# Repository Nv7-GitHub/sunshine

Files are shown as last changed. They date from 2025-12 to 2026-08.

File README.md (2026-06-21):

# Sunshine Combat Robot
This is the code for a 1lb melty-brain combat robot. This is a combat robot whose body spins and the wheel speeds are modulated while spinning for translation. There are 3 main components to this robot:

- Robot brain (sunshine_brain): ESP32-S3, which reads the sensors, does the processing, and sends the telemetry via ESP-now to the receiver and receives motion commands and safety-related commands (e.g. enable, disable, etc.)
- Receiver (sunshine_receiver): ESP32-S3, which receives the telemetry and sends it to the host app as well as sends out telemetry commands from the host app
- Host app (sunshine_app): Graphs data, displays telemetry, saves logs to files, handles replay (has to interact with sunshine_brain code for this) and simulation

## Tech stack
All embedded code will be implemented via platform IO. The host app code will be Tauri with React for the frontend. For replay (explained below), the brain code that is above the IO layer has to be very encapsulated so that it can be called from the Tauri rust code.

## Replay
The core concept of this project is IO layers and replay. The core sensors: **time (precise)**, wheel eRPM, ESP-NOW RSSI, magnetometer reading, battery voltage, control inputs from the driver, and accelerometer readings are all sampled at 1kHz and logged via telemetry. 

All the brain code processes these inputs (which are below the IO layer) and runs code that affects the **state**. The state is every variable that changes over time as a result of previous inputs. This should just be the external and internal states of any filters being used. 

The telemetry packets are sent out at 50 Hz, so each packet should include two state snapshots — one at the start of the packet and one at its midpoint (the 10th of its 20 samples), giving the real state at 100 Hz — and then the 20 IO layer samples that happened since the start state. The two states let the host both initialize the filters and double-check the replay against the real state twice per packet. This will minimize data usage because the host app can simply receive the state to initialize the filters and then run replay from there on. In the log files, the real state is likewise logged at 100 Hz (two snapshots per 50 Hz frame; theoretically you could even do it once but I want to be able to always have something to double-check the replay against and/or a way to handle changed code since you collected the telemetry) and the data below the IO layer is logged at the full 1kHz. Variables are NOT logged — they are a pure function of state + inputs, so the host always recomputes them (both the real and replayed versions).

The replay should use the ACTUAL robot code and just feed it a different source of IO layers instead of the raw sensors. So if you make a code change, you could re-run the code using the logged telemetry data and see if it fixes a bug that is occurring, for example.

This IO layer concept is important because it lets you implement simulation, where instead of having the receiver managing state you just implement a basic simulation of the motors and how it affects the sensors in an ideal world and then you can simulate the robot fully on the computer, once again just feeding the simulated sensor data into the IO layer.

In addition to the **state** and **inputs** (data below the IO layer) you also have the **variables** - data that is calculated from the state or inputs without any historical components. This is also logged at 50 Hz, but never sent over telemetry, just logged by the host app. This is once again so that if code changes occur you don't lose the data that was produced by the old code, which is necessary for determining if changes actually led to fixes. 

Replay is designed with AI assistance in mind. Develop Claude skills to aid with debugging code with validation via replay and simulation in parallel to this. Design everything with debugging and ugpradeability in mind. Changing what's in the state, what the inputs are, etc. should be easy and backwards-compatible (so old log data should still be usable). Adding a new variable (especially to the state and variables, which I anticipate changing a lot) should be very easy and well documented for future AI sessions along with the codebase in general.

## Robot brain

The robot brain has the two components mentioned before: below the IO layer, and above the IO layer. Everything above the IO layer has to be able to be run both on the host computer as well as the robot, so it should never interact with hardware directly and should be able to easily be compiled and run on a variety of host computer platforms. For below the IO layer, here is the hardware map:

## Hardware map
IMU is an ADXL375, 11mm from the center of the robot (this is important for calculating ang vel from the centripetal accel). The IMU is rotated 45 degrees so it saturates less.
- IO8: IMU_INT1
- IO9: IMU_INT2
- IO10: IMU_CS
- IO11: IMU_MOSI
- IO12: IMU_SCK
- IO13: IMU_MISO

Mag is LIS3MDL
- IO14: MAG_DRDY
- IO15: MAG_MOSI
- IO16: MAG_SCK
- IO17: MAG_MISO
- IO18: MAG_CS
- IO21: MAG_INT

There is an LED connected to IO38 that can be PWMed. It's connected to the gate of a low side switch so you drive it high to turn on the LEDs.

IO7 is connected with a voltage divider (2kohm high, one kohm low) to the battery positive terminal

IO4 is the signal pin of the left wheel ESC (S1), IO5 is for the right wheel ESC (S2). Use bidirectional DShot 600.

USB is connected, so you can use USB for debugging info

## Core splitting
There are 3 overall tasks running on the brain: telemetry, navigation, and control. 

### Telemetry
Telemetry should be running on the ESP32 core that is meant for telemetry. The data is getting sent out at a fixed 50 Hz and should be received from the transmitter at 500 Hz. This core should receive state (the history, or maybe it buffers the history itself but as explained earlier in each packet there's the state and then the 50 subsequent inputs). This core also uses the RSSI from the receiver and sends it over to the control core as this is one of the inputs. The receiver and transmitter should be configured to send at the absolute max strength, and the transmitter should be sending without waiting for acknowledgement or anything. For the telemetry it should be robust since any missing data will mess up replay, so determine a protocol that is able to do that without causing congestion so the packets with RSSI and control inputs can be sent at the 500 Hz. This is in a very RF noisy environment so account for that appropriately.

IMPORTANT: When the robot is disabled in the host app, it HAS to disable in real life. This is a strict requirement as it is critical to safety.

### Navigation
Navigation is the 1kHz sensor read and filter update loop. All the sensors can be read at 1kHz or faster (make sure to configure correctly) and all are connected via SPI so it should be fast. The filter is as follows:
- The accelerometer data is used to determine angular velocity. When being transmitted, this is an int16
- The magnetometer data goes through a butterworth filter with a cutoff roughly in the range of what Earth's magnetic field should be oscillating at. Calculate the minimum speed needed before zero DC leaks through and set that as the minimum speed to use this sensor, as there will be a lot of DC offset due to current draw from the ESC and various metallic objects. The raw reading is also an int16 for telemetry. The filter will be part of the state (and needs appropriate history). 
- The wheel ERPM is not going to be used for anything navigation-related. However, it can be used for torque-limiting and for looking at things like wheel slip in the logged data after. Log this as a float16.
- The RSSI is from the actual ESP-NOW receiving data. This is an int8. This is eventually going to be worked into the filter but I think the shape of it's curve depends on antenna stuff so I will collect some data not using it initially and try to analyze it before incorporating it into anything. 
- The host computer sends x, y, theta, and throttle. X/Y/Theta are all int8 and throttle is uint8. 
- The battery voltage can be represented as a int8, relative to 7.6V (the robot is 2S). The range needs to go to 5.0V and be symmetrical.
- Put the applied DShot signals into the inputs too, but quantize down to uint8 for each since I just want to see the overall shape at 1kHz, it is never going to be used anywhere.
- Time should be of the necessary precision to be accurate down to a decimal OF the control loop (so since the loop is at 1kHz, it should be accurate to ten-thousandths of a second) which means a uint32 is needed.

Make sure to consider endian-ness correctly for telemetry or use some protocol.

The overall Kalman filter will use the magnetometer as an absolute reference (since with the DC filtered out from the butterworth it should actually represent absolute position), the accelerometer gives velocity for the kalman filter, and eventually the RSSI will either give velocity or position but that is to be determined. 

The theta control defines an offset from the absolute position from the magnetometer. That way the driver can rotate the zero heading reference. 

The kalman filter will need to be tuned somewhat. Develop necessary code (this will probably happen during bringup) and include instructions to tune it. 

### Control
Control also happens in the same 1kHz loop. It is CRITICAL that this tight 1kHz loop does not overrun, and I should know about it when it is happening. The inputs include precise time so the host app should be receiving this, and of course loop overruns should be included in the USB output along with any initialization errors for the sensors. Make sure to have a distinct LED pattern if there are initialization errors too with the sensors, since usually I won't have USB connected during init so I would connect USB once I see that pattern (so the error should be continuously printed). 

During control, the LED has to be turned on from -3 deg to +3 deg (of course relative to the driver-controlled zero heading). 

The X and Y controls will be used for translational control. For the translational drift, use triangle waves in a portion of the rotation such that it can drive. The amplitude of the wave should depend on the magnitude of the X/Y control. Write a document on how to tune this (what to change and how that will affect the motion and what I should look for). I am thinking of a triangle wave instead of the usual square because the melty should be traction limited and a triangle wave should limit slip. Maybe a trapezoidal wave instead of a triangle if that would be more optimal.

There are two modes of control. There is DISABLED, which is critical to safety and the host app will control this. Then there is TANK, where the robot is driven around like a traditional robot, so throttle controls forwards backwards and the x control (side-to-side) should determine turning. Y and theta are unused. Finally, there is MELTY where throttle controls target angular speed (for now open-loop), X is for side-to-side, Y is forwards backwards, and theta controls the offset. This is holonomic unlike the previous tank drive mode so you can of course mix the X and Y. In the app design mockup (included below) there is only ENABLED and DISABLED so this needs to be changed to have DISABLED, TANK, MELTY.

## Bringup
There is no way that the entire codebase can be put onto the device and everything will work, so bringup needs to occur where each specific function has to be individually tested. Design a clean way of doing this. Here are the levels of bringup:
1. Low-level sensors: Read the accelerometer, plot via USB, make sure that works, same for the magnetometer, voltage sensor. etc.
2. Low-level control: Test the bidirectional DShot and make sure everything spins up correctly
3. Telemetry link: Test the ESP-NOW connection between the brain and the receiver, including sending the inputs and receiving the RSSI data. At this point the host app has to get in the loop too, and I should be able to plot accel, rssi, etc.
4. Navigation tuning: The kalman filter and other parameters must be tuned so that the device can localize well. At this point I will use the tank mode to spin the robot, MELTY mode will still not be used.
5. Drift tuning: MELTY mode is finally enabled, heading control should be good (so the LED should be solid and still), and I can tune the drift profile

Make sure it is an easy process and write instructions.

# Receiver
The receiver is simply the other side of the link from the robot brain. It should receive the necessary info and send it via USB (it is an ESP32-S3 so should have plenty of bandwidth) to the host app and send data. The accompanying protocols must be developed. 

# Host app
The UI mockup has been made:

## UI Mockup
Fetch this design file, read its readme, and implement the relevant aspects of the design. https://api.anthropic.com/v1/design/h/ER_Esv7z8Q_IkM8_wpP-5Q?open_file=Sunshine+Dashboard.html
Implement: Sunshine Dashboard.html

Note that this mockup has some unnecesary info plotted on top (e.g. CPU usage doesn't make sense, but seeing the bandwidth over the connection or the RSSI would be useful up there), and the variables are fully made up. Instead of ENABLE DISABLE there should be DISABLE, TANK, MELTY. In addition to x-y and throttle there is also the theta control. The current keybinds are:
W/S for Y, A/D for X, left/right arrow for theta, and up/down arrow for throttle (where throttle adds up instead of being like when you let go it goes to zero). This should be HEAVILY low-pass filtered (even more than the current mockup) so that I can basically emulate having a controller by pulsing WASD and the left/right arrow keys.

The connections section of the UI doesn't make sense. Robot is 2S so of course adjust battery indicator colors accordingly. Get rid of the E-STOP button as that's the same as DISABLE. Inputs menu is unneeded. Retain the same graph controls but fix it because right now it's a little jerky and awkward (way too sensitive to the scroll). 

You should be able to do replay, simulation, and connect to the real robot through the UI. Implement that stuff into where the "CONNECTIONS" area is currently. For replay you would pick a log file, simulation just spins up a simulation, and connecting to the robot would connect to the receiver and then look at whether the receiver is connected and all. Error handling will need to be coordinated across all devices in the chain in a robust and extendable manner.

## Logging
The code needs to log a decent amount of data at 50 Hz (where each 50 Hz frame has those 20 inputs). Use binary so the file is small and of course design around the backwards compatibility aspect so that old files can be used with versions of the software that have new variables.

## Plotting
You should be able to plot both the actual 50 Hz data as well as your replayed data for the state variables (this applies when connected to the real robot as well as when replaying from a data file, in simulation it doesn't really make sense but they can probably just be the same thing but one is at 50 Hz). The only reason we replay even when connected to the real robot is so that we can see what's going on at 1kHz, so the replayed data should look like a high-resolution version of the 50 Hz data. Make sure to design the graphing UI such that it can handle the high density of points / quantize since of course rendering at 1kHz when you are showing a minute of data would probably cause lag issues, so consider that when implementing the graphing. 

## Inputs, State, and Variables
All things being plotted have their own units. You can already see this system well implemented in the mockup.

The inputs should all be plotted under the inputs dropdown. Most of the state (e.g. the kalman filter internal covariances, butterworth history) don't make sense to plot so only things like position, velocity, and the magnetometer data after the filter really make sense to plot.

Even though the control outputs are logged at 1kHz as part of the inputs, they will get re-calculated during replay and so there should be a way of viewing the new control outputs too. That's why even though during telemetry they are part of the inputs in the app graphing they should be part of the STATE since they have separate values received vs replayed. We basically have a Real State and a Replayed State which of course includes the 50 Hz things above but also the 1kHz wheel applied values.

The variables are only present in the replayed values, as they are never sent from the robot. Think of all important values. e.g. velocity calculated from the accelerometer would be a variable that should be plotted. All possibly useful info should be plottable.

The app has to call the actual C code to emulate the control and state estimation. This will require calling of C code from Rust. 

## Simulation
Use the basic electrical model of a brushed motor. (Back-EMF source, resistance, etc.). The KV of the motors is 1100KV (this should be an easily editable constant though). I don't know the exact resistance but lets say each phase is 75mohm. The battery is a 2S 650mah 120C LiPo. Don't model battery draining but model internal resistance using like the supply current derived from the stator current in the motor, pick a reasonable internal resistance for a battery with these specs. For the magnetomer, just do ideal earth's magnetic field, same for accelerometer. here are some more physical parameters you need:
- Wheel Diameter: 44mm
- The wheels are 81mm apart (so radius from center is 40.5mm). 
- The MoI of the robot is 1213859.17531 g-mm^2
- Wheel MoI is 6407.44019 g-mm^2
Use metric for everything.

I believe the max body RPM is somewhere around 4,000, you should double check this to ensure I gave you the right-specs.

# General Notes
Everything should be implemented robustly. If everything is connected and setup but then I unplug and replug the receiver, the host app should handle that gracefully and make a new log file. There also should be an easy way to disable logging from the host app. If the robot momentarily loses power or disconnects and then reconnects the host app and receiver should handle this gracefully. The disabled aspect is critical to safety. The code should be very well documented (in MD files) such that future AI sessions can read an info document and know what files to edit. There should be instructions for tuning meant for humans. Also make it easy to label log files (e.g. during comp it should be based on match, but always include date and stuff)

IMPLEMENT SKILLS TO AID WITH DEBUGGING!

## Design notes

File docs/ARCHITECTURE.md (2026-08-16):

# Sunshine Architecture

Codebase map for AI sessions and new contributors. Read this before touching anything.

---

## Repository Layout

```
sunshine/
├── sunshine_core/          # Pure C99 library — NO platform dependencies
│   ├── include/sunshine_core.h   # All structs, constants, full public API
│   └── src/
│       ├── utils.c         # float16, wrap_to_pi, clampf, unit conversions
│       ├── kalman.c        # 2-state Kalman filter (θ, ω): predict + two updates
│       ├── mag_heading.c   # Open-loop mag heading (spin-tracking RBJ band-pass + atan2)
│       ├── control.c       # DISABLED / TANK / MELTY logic, trapezoid wave, LED
│       └── brain.c         # sunshine_step() top-level, serialisation, state_init
├── sunshine_brain/         # PlatformIO ESP32-S3 brain firmware
│   ├── lib/sunshine_core/  # Symlinks to ../sunshine_core/ (PlatformIO lib)
│   ├── include/
│   │   ├── bringup.h       # BRINGUP_LEVEL compile-time feature gates
│   │   └── config.h        # Pin assignments, MAC addresses, timing constants
│   └── src/
│       ├── main.cpp        # setup/loop, error LED patterns, FreeRTOS task launch
│       ├── sensors/        # adxl375.cpp + lis3mdl.cpp — SPI driver wrappers
│       ├── dshot.cpp       # Bidirectional DShot 600, eRPM telemetry read
│       ├── ring_buffer.h   # Lock-free SPSC ring buffer (Core1→Core0, 40 entries)
│       ├── telemetry.cpp   # Core 0 task: ESP-NOW TX/RX, drain ring buffer
│       └── nav_control.cpp # Core 1: 1 kHz hard-real-time loop
├── sunshine_receiver/      # PlatformIO ESP32-S3 receiver firmware
│   ├── include/
│   │   ├── config.h        # Brain MAC, timing constants
│   │   ├── protocol.h      # USB frame format, encode/decode, FrameParser
│   │   └── led_status.h    # Onboard RGB status LED API
│   └── src/
│       ├── main.cpp        # WiFi+ESP-NOW init, task creation, LED init
│       ├── espnow_rx.cpp   # Core 0: ESP-NOW RX callback, double buffer
│       ├── usb_bridge.cpp  # Core 1: USB TX/RX, 500 Hz ESP-NOW TX, watchdog, LED drive
│       └── led_status.cpp  # Non-blocking WS2812 status LED (link/liveness)
├── sunshine_app/           # Tauri + React host application
│   ├── src-tauri/src/
│   │   ├── ffi.rs          # sunshine_core C bindings + safe wrappers (unsafe here only)
│   │   ├── serial.rs       # USB serial port management + reconnect loop
│   │   ├── protocol.rs     # USB frame encode/decode
│   │   ├── pipeline.rs     # Central data pipeline, ring buffer, drives all sources
│   │   ├── replay.rs       # .sun file reader + replay engine
│   │   ├── simulation.rs   # Brushed DC motor + robot kinematics physics model
│   │   ├── logging.rs      # .sun file writer
│   │   ├── controls.rs     # Latest control state management
│   │   └── commands.rs     # All Tauri command handlers (JS-callable)
│   └── src/
│       ├── components/Header.tsx          # Mode buttons, status bar, logging control
│       ├── components/ConnectionPanel.tsx # Live/Replay/Sim tabs
│       ├── components/GraphPanel.tsx      # uPlot canvas + channel selector
│       └── hooks/useKeyboard.ts          # Key → filtered control values → Rust
├── sunshine_pcb/           # KiCad PCB design files
├── tools/
│   └── gen_filter_coefficients.py        # Generates LP4 biquad coefficients
└── docs/
    ├── ARCHITECTURE.md     # This file
    ├── BRINGUP.md          # Step-by-step hardware bringup instructions
    ├── TUNING.md           # Kalman + drift tuning guide
    ├── FILTER_MATH.md      # Plain-language explanation of the full filter chain
    ├── DEBUGGING.md        # Instructions for sunshine:replay-debug Claude skill
    └── superpowers/
        ├── specs/          # System design spec (source of truth)
        └── plans/          # Implementation plans (per subsystem)
```

---

## Data Flow

```
LIVE:       Brain sensors
              → 1 kHz sunshine_step() on ESP32
              → ESP-NOW v2 (50 Hz, 20 inputs/frame, 715 B) → Receiver
              → USB serial (715 B payload + 5 B framing) → Tauri serial.rs
              → pipeline.rs: brain_step() × 20 → ring buffer → live_update event
              → React GraphPanel

REPLAY:     .sun file → replay.rs reads frames
              → pipeline.rs: brain_step() × 6 (at controllable speed)
              → same ring buffer + events path as LIVE

SIMULATION: simulation.rs ticks at 1 kHz → SunshineInput
              → pipeline.rs: brain_step() → SunshineVars
              → simulation.rs applies dshot_cmd_left/right → next tick
              → same ring buffer + events path
```

---

## Module Responsibilities

### `sunshine_core` — Pure C island

**The single rule:** no ESP-IDF, no FreeRTOS, no OS calls. Only C99 standard library (`math.h`, `stdint.h`). Compiles identically on ESP32 and desktop.

**Entry point:** `sunshine_step(in, state, vars_out)` — pure function, no side effects except mutating `*state`. Identical inputs + state → identical output. This is what makes replay and simulation possible.

**Internal call sequence inside `sunshine_step()`:**
1. Decode raw inputs → `vars->centripetal_ms2`, `omega_from_accel`, battery, eRPM
2. `kalman_predict()` — dead-reckoning: θ += ω·dt, propagate covariance
3. `mag_heading_step()` — open-loop spin-tracking band-pass + atan2 → mag_angle (absolute);
   also refreshes `spin_rate_lp` (signed mag rotation rate) and `spin_freq_lp` (band-pass centre)
4. `kalman_update_omega()` — rate update. Source = the **accel magnitude** with the
   **mag's sign** (`spin_rate_lp` gives CW/CCW; skip if accel saturated). The v5
   mag-rotation-rate source was reverted 2026-08-15 — in-band AC interference beats
   wobble `mag_angle`, and differentiating that into a rate amplified the wobble
   (see the brain.c rate-update comment and TUNING.md)
5. `kalman_update_theta()` — mag measurement update (skip if ω < 16π rad/s ≈ 480 RPM)
6. `control_step()` — DISABLED/TANK/MELTY → dshot_cmd_left/right, led_on

### `sunshine_brain` — Core assignment

- **Core 1** (priority 10, pinned): 1 kHz nav+control loop. Reads sensors, calls `sunshine_step()`, sends DShot, pushes to ring buffer. Never blocks on telemetry.
- **Core 0** (priority 5): Telemetry task. Drains ring buffer → assembles 50 Hz ESP-NOW frames (20 inputs + state) → sends to receiver. Receives 500 Hz control packets from receiver → stores behind mutex.

### `sunshine_receiver` — Bridge role

- **Core 0**: ESP-NOW RX callback stores brain telemetry in a double buffer, signals Core 1.
- **Core 1**: USB bridge loop — forwards telemetry frames to host, reads USB from host, forwards controls to brain. A FreeRTOS-independent `esp_timer` at 500 Hz sends the latest control packet to the brain regardless of host cadence.
- **Host watchdog**: If no USB packet from host for 3 seconds, forces `mode=DISABLED` before sending to brain.
- **Status LED**: The onboard WS2812 RGB LED (`led_status.cpp`, GPIO48 via `RGB_BUILTIN`) shows liveness and link state — driven each bridge tick from the existing brain-connected and host-watchdog signals. See the LED legend in `BRINGUP.md`.

### `sunshine_app` — Tauri backend

**`ffi.rs`** is the only file with `unsafe`. All `sunshine_core` C calls go through here.

**`pipeline.rs`** is the central hub — all three source modes (live/replay/sim) converge here after producing `SunshineInput`. It calls `brain_step()`, writes to the ring buffer, triggers logging, and emits `live_update` events to React.

**`simulation.rs`** implements brushed DC motor physics (KV=1100, R=75 mΩ), battery model (8.4V, 8 mΩ internal resistance), and robot body dynamics (MoI=1.214e-3 kg·m²). It feeds DShot outputs from `SunshineVars` back as motor commands each tick.

---

## IO Layer — The Contract

Nothing crosses the core/platform boundary except through these three structs. All defined in `sunshine_core.h` with `__attribute__((packed))`:

| Struct | Size | Direction | Description |
|---|---|---|---|
| `SunshineInput` | 30 B | Hardware → core | 1 kHz sensor frame (schema v5: `batt_offset` is int16) |
| `SunshineState` | 56 B | Core ↔ core | Filter history (Kalman + mag band-pass + spin-sign + `spin_freq_lp`) |
| `SunshineVars` | 56 B | Core → hardware | Derived variables, computed each step |

`SunshineVars` is never telemetered (schema v4 logs) — it is always recomputed from `SunshineInput` + `SunshineState` via `sunshine_step()`. Each 50 Hz frame stores two `SunshineState` snapshots (frame start and midpoint) plus twenty 1 kHz inputs; replay recomputes vars at 1 kHz.

---

## Append-Only Rule

**Fields may only be added to the END of `SunshineInput`, `SunshineState`, or `SunshineVars`. Never insert, reorder, or resize existing fields.**

The one deliberate exception is the schema-v5 `batt_offset` widening (int8→int16, a mid-struct resize for finer battery resolution). Because the log reader is a raw byte copy keyed on the header's `sizeof_input`, a resize would silently corrupt the trailing `mode`/`dshot_*_q` bytes of pre-v5 logs (→ they'd replay as DISABLED). So the reader is made **schema-aware** for that field: `replay.rs::read_input` and `tools/replay/replay.c::unpack_input` branch on `schema_version` (< 5 → old int8 layout, remapped to the int16 LSB scale). Prefer plain append for future changes; only resize with a matching reader branch.

`SUNSHINE_SCHEMA_VERSION` (currently 5) must be bumped with a comment on every struct change. Log files store `sizeof_input`, `sizeof_state`, `sizeof_vars`, and `num_inputs` in the header; readers handle mismatches:
- Reader's `sizeof < file's sizeof`: truncated read, extra bytes skipped
- Reader's `sizeof > file's sizeof`: missing trailing fields default to zero

This rule means old log files always remain readable without converter functions.

---

## Safety Architecture

Three independent watchdogs ensure the robot stops within ≤3.5 seconds of any broken link:

1. **Host app** → sends any USB packet → resets receiver's watchdog timer
2. **Receiver** → if silent > 3 s, forces `mode=DISABLED` in the 500 Hz control stream
3. **Brain** → if no control packet for 500 ms, forces `input.mode = DISABLED`
4. **`sunshine_step()`** → `DISABLED` mode unconditionally zeroes DShot outputs (structural — not a conditional check)

---

## Key Constants

All physical/tuning constants are in `sunshine_core/include/sunshine_core.h`. Firmware-specific constants (pin assignments, MAC addresses) are in `sunshine_brain/include/config.h` and `sunshine_receiver/include/config.h`.

| Constant | Value | Where |
|---|---|---|
| `ADXL_SCALE_MS2` | 49e-3 × 9.81 | sunshine_core.h |
| `MAG_SCALE_UT` | 0.058 µT/count | sunshine_core.h |
| `IMU_RADIUS_M` | 0.011 m | sunshine_core.h |
| `SUNSHINE_MAG_MIN_OMEGA` | 16π rad/s (~480 RPM) | sunshine_core.h |
| `KF_Q_THETA/OMEGA` | 1e-6 / 1e-2 | sunshine_core.h |
| `KF_R_ACCEL/MAG` | 0.5 / 0.01 | sunshine_core.h |
| `MAG_BP_FC_LP_HZ` | 1.5 Hz | sunshine_core.h (band-pass centre LP) |
| `BATT_SCALE_V` | 0.001 V/LSB (int16) | sunshine_core.h |
| `DRIFT_PLATEAU_WIDTH` | 0.35 | sunshine_core.h |
| `DRIFT_AMPLITUDE` | 0.40 | sunshine_core.h |
| `DRIFT_PHASE_OFFSET_RADS` | 0.0 rad | sunshine_core.h |
| `DRIFT_PHASE_LEAD_S` | 0.0 s | sunshine_core.h |
| Loop interval | 1000 µs (1 kHz) | config.h (brain) |
| ESP-NOW TX rate (brain→rx) | 50 Hz | Derived: 20 inputs/frame over ESP-NOW v2 (715 B) |
| ESP-NOW TX rate (rx→brain) | 500 Hz | config.h (receiver) |
| Host watchdog | 3 s | config.h (receiver) |
| Brain watchdog | 500 ms | config.h (brain) |

---

## Known Platform Issues

**pioarduino `stable` URL**: The brain's `platformio.ini` references the pioarduino `stable` release URL. As of 2026-05-26 this URL fails with `MissingPackageManifestError`. See `BRINGUP.md` for the workaround.

**Receiver IDF version**: The receiver is built against `espressif32@6.0.0` (IDF 4.4). IDF 4.x uses a different `esp_now_recv_cb_t` signature (no `esp_now_recv_info_t`), so receiver-side RSSI is not available from the callback — `espnow_rx_get_rssi()` returns -127 until rebuilt on IDF 5.x. Brain-side RSSI (`inputs.rssi`) works normally.

**DShot library**: `platformio.ini` uses `derdoktor667/DShotRMT @ ^0.9.5` rather than `qqqlab/DShotRMT_NEO`. The API is similar but check the library examples if arming or eRPM telemetry behaves unexpectedly.

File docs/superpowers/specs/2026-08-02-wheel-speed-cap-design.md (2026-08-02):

# Wheel-Speed Cap & eRPM Signal Integrity — Design

**Date:** 2026-08-02
**Status:** Approved for planning
**Evidence log:** `~/Documents/sunshine_logs/2026-07-20_04-20-24_translation2.sun`
(405 s total, 224 s in MELTY, schema v5 / FILE_FORMAT_VER 3)

---

## 1. Problem

The robot bounces vertically while spinning in MELTY. One contributing cause is
visible directly in the eRPM telemetry: the wheels spin up far faster than the
ground demands, then are dragged back down every time they touch. Each landing
dumps the stored wheel kinetic energy into an impulsive traction spike, which
throws the robot back into the air, and the cycle repeats.

This design addresses that one cause. It does not claim to be the only cause of
the bouncing.

A second, independent problem obstructs debugging: the logged eRPM stream is
untrustworthy — it reads zero for long stretches and occasionally spikes — so
the very signal needed to diagnose wheel behaviour cannot be read at face value.

---

## 2. Evidence

All numbers below are measured from the evidence log. **None of them are
compiled into the firmware.** They exist to justify the choice of round,
robot-independent default constants; see §3.6.

### 2.1 The wheels overspeed

With no slip, wheel angular rate is set by geometry:

```
w_wheel = |w_body| * WHEEL_CENTER_M / WHEEL_RADIUS_M
eRPM    = w_wheel * 60/(2*pi) * POLE_PAIRS  =  123.06 * |w_body|
```

Measured `erpm_left` divided by that expectation, over mag-valid spin:

| percentile | p5 | p25 | p50 | p75 | p95 |
|---|---|---|---|---|---|
| ratio | 1.05 | 1.17 | **1.30** | 1.55 | 2.27 |

The wheels typically run 30 % faster than the ground demands, and up to 2.3×.

### 2.2 The ESC is an open-loop voltage source

Predicted no-load eRPM is `duty * V_batt * KV * POLE_PAIRS`, where
`duty = (dshot - 1048) / 999`. Measured against that, using the **logged**
battery voltage:

| percentile | p5 | p25 | p50 | p75 | p95 |
|---|---|---|---|---|---|
| measured / nameplate no-load | 0.495 | 0.789 | **0.936** | 1.038 | 1.587 |

The wheels run at 94 % of the no-load speed their command implies — a median
deficit of **0.139 V** out of a median 2.489 V applied. That deficit is the
`I·R` drop under load, not an error in KV: pairing it with the median 1.15 A
derived independently from body acceleration (§2.4) gives R ≈ 0.12 Ω, matching
§2.4's estimate.

Two consequences:

- Wheel speed is set by `duty × V_batt`, so **battery voltage must appear in the
  cap**. Battery ranged 7.80–8.39 V within this single log — a 7 % speed swing
  for an unchanged DShot value.
- Because the wheels sit within 6 % of no-load speed, the motors are producing
  very little torque, which means very little traction force. Body acceleration
  over the 205–215 s spin-up was only **α ≈ 9 rad/s²**. The wheels were slipping
  uselessly, not driving the robot.

### 2.3 Drivetrain geometry is confirmed

A wheel cannot roll *slower* than the ground unless it is braking, so if the
geometry constants are right the measured ratio from §2.1 must have a hard floor
at 1.0. Over 113 k driven, mag-valid samples:

| percentile | 0.5 % | 1 % | 2 % | 5 % | 25 % | 50 % |
|---|---|---|---|---|---|---|
| left  | 0.885 | 0.974 | 1.012 | 1.055 | 1.169 | 1.298 |
| right | 0.178 | 0.912 | 0.973 | 1.026 | 1.155 | 1.283 |

The floor lands on 1.00 within ~2 %. A 10 % geometry error would have placed it
at 0.90 or 1.10. `WHEEL_RADIUS_M = 0.022`, `WHEEL_CENTER_M = 0.0405` and
7 pole pairs are therefore correct for this build.

### 2.4 Effective winding resistance

Deriving per-motor current from body acceleration
(`I = MOI*alpha*WHEEL_RADIUS_M / (2*WHEEL_CENTER_M*Kt)`) and slip voltage from
`duty*V_batt - rpm/KV`, over 37.6 k samples with α > 15 rad/s²:

| | p10 | p25 | p50 | p75 | p90 |
|---|---|---|---|---|---|
| R = ΔV/I (Ω) | 0.022 | 0.089 | **0.159** | 0.237 | 0.336 |

Roughly 2× the 0.075 Ω assumed in `simulation.rs`. This is an **upper bound** —
the estimate neglects bearing and tire drag, which understates the current truly
required and so overstates R. The independent aggregate cross-check in §2.2
(median 0.139 V deficit ÷ median 1.15 A) gives R ≈ 0.12 Ω, so the true value
lies somewhere in 0.12–0.16 Ω.

Slip voltage the robot actually used while accelerating: **median 0.197 V,
p90 0.431 V**.

### 2.5 eRPM zeros are unmeasurable samples, not stopped wheels

Zeros occur in **77.6 %** of samples where the command is at neutral, and in
**0.01 %** of driven samples. Bidirectional-DShot eRPM is derived from the ESC's
own commutation timing; at zero throttle AM32 turns the FETs off and coasts, so
there is nothing to time and it emits a decaying, meaningless period.

The decisive observation is at t = 402.9 s, where the command drops to 0 while
the body rate stays flat at −94 rad/s:

| t (s) | kf_omega | dshot | erpm_left |
|---|---|---|---|
| 402.90 | −94.0 | 1364 | 18416 |
| 402.91 | −94.7 | 0 | 15784 |
| 402.93 | −93.8 | 0 | 9864 |
| 402.95 | −99.1 | 0 | 5340 |
| 402.97 | −94.1 | 0 | 3408 |
| 402.98 | −94.8 | 0 | **25504** |
| 403.02 | −94.3 | 0 | 3312 |

Body ω is unchanged across the window, so the flywheel — and therefore the
wheels — cannot have slowed. The wheels are provably still turning at
~11 500 eRPM while the ESC reports ~3 300 with a 25 504 spike. **Zero means
"no measurement", not "stopped".**

Residual defects on *driven* samples: 0.07 % of decodes exceed 40 000 eRPM, with
single-tick jumps up to 58 000.

---

## 3. Design — the wheel-speed cap

### 3.1 Principle

Because the ESC is an open-loop voltage source (§2.2), the wheel's steady speed
is a known function of the command. Invert it: compute the DShot value whose
no-load speed equals the speed the ground demands, plus a fixed allowance for
slip, and clamp the commanded value to that.

### 3.2 Formulation

In `control.c`, MELTY branch only:

`v_batt` is `v->batt_voltage`, which `brain.c` already computes from
`in->batt_offset` before calling `control_step()`.

```
w_ref    = max(locked ? |s->kf_omega| : 0, SUNSHINE_MAG_MIN_OMEGA)   # rad/s, body
w_roll   = w_ref * WHEEL_CENTER_M / WHEEL_RADIUS_M                   # rad/s, wheel
w_cap    = w_roll + WHEEL_SLIP_ALLOW_MS / WHEEL_RADIUS_M
v_needed = (w_cap * 60/(2*pi)) / MOTOR_KV_RPM_PER_V
cap      = DSHOT_NEUTRAL + (v_needed / v_batt) * (DSHOT_MAX - DSHOT_NEUTRAL)
base     = min(base, max(cap, DSHOT_NEUTRAL))
```

`locked` is `v->mag_valid && fabsf(s->spin_rate_lp) > SUNSHINE_MAG_MIN_OMEGA` —
the exact condition `brain.c` already uses to decide whether to trust the mag
rate over the accel.

### 3.3 Why the reference rate is `max(..., SUNSHINE_MAG_MIN_OMEGA)`

Losing lock does not mean ω is unknown. Lock is *defined* by
`|kf_omega| > SUNSHINE_MAG_MIN_OMEGA`, so "not locked" carries the bound
`|omega| <= SUNSHINE_MAG_MIN_OMEGA`. The cap therefore never switches off; it
falls back to the threshold. Because `locked` implies
`|kf_omega| > SUNSHINE_MAG_MIN_OMEGA`, the single `max()` expression is
continuous across the lock boundary.

At 8.2 V the unlocked ceiling is ≈ 1194 DShot, which still permits 3.03 m/s of
slip at standstill (≈ 7.5 A, ≈ 2.96 N per wheel against a carpet friction limit
near 2.2 N). Spin-up from rest therefore remains fully traction-limited and is
not slowed by the cap, while the runaway is bounded at all times rather than
only after lock.

### 3.4 Why the rate must come from the magnetometer, not the accelerometer

`omega_from_accel` is corrupted precisely when the cap matters most: while the
robot is airborne or impacting, the accelerometer sees free-fall and impact
rather than centripetal acceleration, so the accel-derived rate spikes and would
*raise* the cap at the worst possible moment. `kf_omega` driven by the mag
rotation rate is immune to linear acceleration (see `brain.c` rate-update
comment) and is the only trustworthy reference during a bounce.

### 3.5 Why a fixed slip *speed*, not a percentage

Traction force comes from `I = (V_cmd - backEMF) / R`, so a fixed slip *voltage*
buys a fixed current and hence a fixed torque at any spin rate. A fixed slip
speed is a fixed slip voltage. Expressed as a percentage of rolling speed, the
1.0 m/s default is:

| body rate | 50 rad/s | 100 rad/s | 150 rad/s |
|---|---|---|---|
| margin | 50 % | 25 % | 17 % |

A flat 20 % would starve the robot at low spin while still permitting runaway at
high spin.

### 3.6 Constants

Added to the `Physical / sensor constants` block of `sunshine_core.h`, alongside
the existing `IMU_RADIUS_M`, and documented as **per-build parameters taken from
the mechanical design and motor spec sheet** — a different robot changes these
four values and nothing else:

| constant | value | source |
|---|---|---|
| `WHEEL_RADIUS_M` | 0.022 | mechanical design (confirmed §2.3) |
| `WHEEL_CENTER_M` | 0.0405 | mechanical design (confirmed §2.3) |
| `MOTOR_KV_RPM_PER_V` | 1100.0 | motor nameplate |
| `MOTOR_POLE_PAIRS` | 7 | motor spec (14 poles) |
| `WHEEL_SLIP_ALLOW_MS` | 1.0 | tuning knob, see below |

**No data-fitted value enters the firmware.** `MOTOR_KV_RPM_PER_V` is the 1100
nameplate. The 6 % speed deficit measured in §2.2 is *not* a KV error to be
corrected out — it is the `I·R` drop under load, which is exactly the slip doing
its job. The cap commands a **no-load** speed; the load then pulls the actual
wheel speed below it, and that difference is the torque-producing slip. Nothing
needs to be derated.

This gives the cap two clean guarantees:

- **Overspeed bound.** With the wheel unloaded — airborne, which is the case
  that matters — actual speed equals commanded no-load speed, so overspeed is
  bounded at exactly the allowance.
- **Torque budget.** With the wheel fully gripping, the entire allowance appears
  across the winding: `I_max = WHEEL_SLIP_ALLOW_MS / WHEEL_RADIUS_M * 60/(2*pi)
  / MOTOR_KV_RPM_PER_V / R`.

`WHEEL_SLIP_ALLOW_MS = 1.0` is justified, not fitted. It is 0.395 V of slip
voltage, which is **2× the median slip voltage (0.197 V) and about equal to the
p90 (0.431 V) the robot used while accelerating** (§2.4). It therefore preserves
essentially all acceleration the robot has ever demonstrated while removing the
1.3–2.3× overspeed. Against the upper-bound R from §2.4 it supports
α ≈ 66 rad/s², and against the §2.2 cross-checked R ≈ 0.12 Ω it supports
α ≈ 87 rad/s² — versus the 9 rad/s² actually achieved in the evidence log.

### 3.7 Scope of the clamp

The cap applies to `base` — the mean wheel command — and `headroom` is
recomputed from the capped base so the drift differential scales down with it.
The drift wave still rides above and below the capped base, so the driving wheel
briefly exceeds the cap while the other brakes; that asymmetry *is* the
translation mechanism and must not be clamped away.

The cap applies to MELTY only. TANK is direct driver control with no valid
rate reference.

### 3.8 Failure handling

If `v_batt` is implausible (< 5 V or > 10 V) the cap is skipped entirely
(fail-open). A stuck-low battery reading must not disarm the weapon mid-match.

### 3.9 Accepted consequence

A robot with a dead magnetometer never achieves lock and is therefore held at
the §3.3 unlocked ceiling, stalling out near 50–60 rad/s instead of spinning up
freely. A MELTY robot with no heading reference cannot be driven anyway, so this
is the right trade — but it converts "degraded but spinning" into "will not spin
up", which must be documented where bringup will see it (`BRINGUP.md`,
`DEBUGGING.md`), not left to be discovered in a match.

---

## 4. Design — eRPM signal integrity

### 4.1 Represent "unmeasurable" as NaN

When the ESC is not commutating, the eRPM field carries **NaN** rather than 0.
This costs no schema bump and no extra bytes — float16 already has NaN
encodings — and it restores the meaning of 0 to "a genuinely stopped wheel".
If eRPM is ever consumed by a control path, NaN fails loudly where a fake 0
fails silently.

`sunshine_f32_to_f16()` currently collapses NaN to +inf: it discards the
mantissa whenever `exp >= 31` (`utils.c:33`). It must preserve a non-zero
mantissa so NaN round-trips as NaN.

### 4.2 Brain-side filter hardening (`dshot.cpp`)

Three defects, only one of which the current `ErpmFilter` addresses:

1. **The escape hatch can flush downward.** `ERPM_ESCAPE = 6` flushes the median
   ring to a new level after 6 consecutive out-of-band decodes in *either*
   direction. Upward that is correct — spin-up is genuinely fast. Downward it is
   physically impossible: the flywheel cannot lose half its speed in 6 ms. Keep
   the fast escape for increases; require a sustained run on the order of 50 ms
   for decreases.
2. **The ceiling is a fixed 65 000**, so it only catches the +inf case. A
   command-derived ceiling is now available for free from the same model the cap
   uses — a wheel cannot exceed `duty * V_batt * KV * POLE_PAIRS` by more than a
   modest regen margin. This rejects the 25 504-while-coasting class of spike
   that 65 000 never will. It requires `dshot_send()` to receive the duty and
   battery voltage, both of which `nav_control.cpp` already holds.
3. **Undriven decodes must not enter the filter at all.** Below the commutation
   threshold, feed nothing and emit NaN. Today that garbage poisons the median
   ring and is then escaped-to.

### 4.3 Host / UI must render NaN as a gap

The UI is where the gap has to appear, but the backend currently destroys NaN
before it arrives. Both need the minimum change to deliver and draw it:

- **`pipeline.rs:488` — `downsample_min_max`.** Rust's `f32::min`/`f32::max`
  *ignore* NaN, so `fold(f32::INFINITY, f32::min)` silently drops NaN from a
  mixed bucket and returns `(+inf, -inf)` for an all-NaN bucket. Make it
  NaN-aware: an all-NaN bucket yields NaN; a mixed bucket yields the finite
  min/max; ±inf is never emitted.
- **`UPlotCanvas.tsx:105` — `spanGaps: true` is global.** The app already uses
  null-as-gap to mean "sparse series" for the coarse 100 Hz `real.*` channels and
  deliberately bridges across them. NaN needs to mean "no measurement, draw
  nothing", so the two must stop sharing one representation. `spanGaps` becomes
  per-series: `true` for sparse `real.*` channels, `false` for dense channels
  where a hole is a genuine absence of measurement.
- **`pipeline.rs:561` — `input.erpm_left/right`** currently plots the raw
  float16 *bit pattern* cast to f32. This is already meaningless and would
  render NaN as a ~64 000 spike. Decode it properly.

serde_json maps every non-finite f32 to `null`, which is the representation uPlot
consumes; the fix above ensures only true NaN reaches that path.

---

## 5. Verification

- **`sunshine_core` unit tests** (`test_control.c`): cap falls back to the
  threshold rate when unlocked; cap tracks `|kf_omega|` when locked; commanded
  no-load speed lands at rolling + allowance; cap scales inversely with
  `v_batt`; the drift wave still rides above the capped base; fail-open on an
  implausible battery reading; continuity across the lock boundary.
- **`f16` NaN round-trip test** — both directions, plus the existing finite
  values as a regression guard.
- **Replay over the evidence log** — a new `tools/replay/wheel_slip.py`
  reporting commanded vs. capped DShot and the resulting slip distribution, so
  the 1.0 m/s default can be confirmed or adjusted against real data rather than
  argument. `real.*` vs `rep.*` shows exactly what the cap would have done to the
  run that bounced.
- **UI check** — load the evidence log, plot `var.erpm_left`, confirm the
  undriven stretches render as gaps while the coarse `real.*` channels still
  bridge.

---

## 6. Documentation

`DEBUGGING.md` gains:

- the machine-local log path (`~/Documents/sunshine_logs`) and how to select the
  newest log;
- an **eRPM interpretation** subsection: NaN = ESC not commutating, not a
  stopped wheel, with the §2.5 coast-down evidence;
- a scenario entry for **wheel overspeed / bouncing**, including the no-slip
  reference figure of 123 eRPM per rad/s of body rate so the ratio is checkable
  at a glance.

`BRINGUP.md` gains the §3.9 dead-magnetometer consequence.

---

## 7. Explicitly out of scope

- **`simulation.rs` tire model.** `MAX_TIRE_FORCE = 25 N` is roughly 10× the
  real carpet friction limit (~2.2 N per wheel), so the simulation will not
  reproduce the bouncing.
- **Vertical dynamics.** The simulation has no vertical degree of freedom, so it
  cannot validate the bounce fix end to end — only the cap arithmetic.
- **The other causes of bouncing.** This design addresses wheel overspeed alone.

Both simulation items are real and both are larger than this change.

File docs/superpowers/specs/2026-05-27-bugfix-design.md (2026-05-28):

# Sunshine App — Bug Fix Design
**Date:** 2026-05-27

## Overview

Twelve confirmed bugs found across the Rust backend and React frontend. Grouped into five areas: simulation, graph/variable-tree data pipeline, controls visualization, top-bar labels, and replay file picker.

---

## 1. Simulation (Backend)

### 1a. Events not delivered — use tokio::spawn

`start_simulation` uses `std::thread::spawn`. Tauri v2 event emission (`app.emit`) may require a tokio runtime context internally. The `let _ = app.emit(...)` silently drops any error. Fix: replace with `tokio::spawn` so the loop runs inside the tokio runtime already present in the Tauri process.

### 1b. No `source_status` event

The frontend `sourceStatus` stays `Disconnected` forever. Fix: emit `{kind:"Sim", detail:"Running"}` immediately when the sim starts, and `{kind:"Disconnected", detail:""}` when it stops.

### 1c. Controls not wired into SunshineInput

The simulation builds `SunshineInput` with `..SunshineInput::default()` for all control fields (`ctrl_x`, `ctrl_y`, `ctrl_theta`, `ctrl_throttle`, `mode`). The brain always runs in DISABLED mode with zero inputs. Fix: clone `state.controls: Arc<Mutex<ControlState>>` and move it into the task. Each tick, lock controls and copy `ctrl_x/y/theta/throttle` and `mode` into the `SunshineInput`.

### 1d. Simulation cannot be stopped

`stop_source` only sets `pipeline.source = SourceKind::None` — it does not stop the simulation task. Fix: add `sim_stop: Arc<AtomicBool>` to `AppState`. `start_simulation` sets it `false` before spawning; the loop checks it each tick and exits on `true`. `stop_source` sets it `true` and emits `Disconnected`.

---

## 2. Graph & Variable Tree Data Pipeline

### 2a. Graph always empty — timestamp mismatch (root cause)

`pipeline::ingest_frame` stores `DataPoint { time_us: input.time_us as u64, ... }`. The hardware `time_us` is a local counter starting near 0 (wraps every ~71 min). The frontend queries `get_graph_data` with `startUs = Date.now() * 1000 ≈ 1.748×10¹⁵ µs`. Every stored point satisfies `dp.time_us < start_us`, so all are filtered. **This affects live, replay, and simulation equally — the graph is always empty.**

Fix: in `pipeline::ingest_frame`, ignore `input.time_us` for the ring buffer timestamp. Instead compute:
```rust
use std::time::{SystemTime, UNIX_EPOCH};
let now_us = SystemTime::now().duration_since(UNIX_EPOCH).unwrap().as_micros() as u64;
```
Use `now_us` as `DataPoint.time_us`. The hardware timestamp is still available inside `DataPoint.input.time_us` for other uses.

### 2b. VariableTree always shows hardcoded `—`

`VariableTree.tsx` renders `—` unconditionally in `var-val`. No live values are ever shown.

**Required behavior:**
- Default: show the latest value from the ring buffer for each channel.
- While cursor is over the graph: show the value at the cursor's x-position (time).
- Cursor leaves graph but window is zoomed in: revert to latest live value.

**Design:**

*New backend command* `get_channel_snapshot(channels: Vec<String>, time_us: Option<u64>) -> Vec<f32>`:
- `time_us = None` → return the value at the most recent ring buffer point for each channel.
- `time_us = Some(t)` → scan backward from ring head to find the point with `time_us` closest to `t`, return its value per channel.
- Returns `f32::NAN` for unknown channels or empty ring. Returns a parallel `Vec<f32>` in the same order as `channels`.

*Shared cursor state:* `App.tsx` holds `cursorUs: number | null`. `UPlotCanvas` receives `onCursorMove: (us: number | null) => void`. Uses uPlot's `cursor.move` hook to call it with the x-axis value converted back to microseconds (`x * 1e6`, since uPlot stores time in seconds), and fires `null` on `mouseleave`. App passes `cursorUs` down to `VariableTree`.

*VariableTree polling:* polls `get_channel_snapshot` at 10 Hz (same interval as graph). When `cursorUs` changes, fires an immediate query. Stores `Map<string, number>` of values. Renders the value (or `—` if NaN/missing) with appropriate precision in `var-val`.

---

## 3. Controls Visualization

### 3a. Theta — replace vertical bar with horizontal slider

The vertical `vbar` for theta is confusing for a bidirectional value. Replace with a horizontal slider element positioned **below the joystick pad** (spanning the same width as the joystick).

Layout: a thin horizontal track (full-width of the joystick) with a filled indicator that slides left (−) to right (+). Center = 0. The indicator width is proportional to `|theta|`. A small circle marks the center-zero. Numeric readout sits below the track.

CSS: add `.hslider`, `.hslider-track`, `.hslider-fill-left`, `.hslider-fill-right` classes. Remove the theta `vbar` from the grid.

Grid change: `controls-grid` changes from `1fr 44px 44px` (joystick + throttle + theta-vbar) to `1fr 44px` (joystick + throttle). Theta slider spans full width below.

### 3b. Joystick history trail

Add a fading trail of the last 30 joystick positions. Store them in a `useRef<{x:number,y:number}[]>` (circular buffer). The RAF loop appends the current position each frame. Render them as SVG `<circle>` elements in the `.joy-grid` SVG, with opacity linearly decreasing from newest to oldest (range: 0.5 → 0.05). Radius: 4px decreasing to 2px.

### 3c. Throttle visualizer lag

Remove `transition: height .08s linear` from `.vbar-fill` in `App.css`. The RAF loop in `ControlsViz` already runs at 60 fps — the CSS transition creates the illusion of lag because it smooths changes instead of tracking the true value. Without the transition, the bar snaps to the exact current value each frame.

---

## 4. Top Bar Labels

| Current | Replace with | Reason |
|---|---|---|
| `ω` | `SPIN` | `ω` (U+03C9) renders identically to Ω (ohm) in most fonts at small sizes; `SPIN` is unambiguous |
| `RSSI·B` | `RSSI·BOT` | `B` was undocumented; `BOT` makes clear it is the robot brain's RSSI, contrasted with `RSSI·RX` (receiver) |

Value formats stay the same.

---

## 5. Replay File Picker

Add `@tauri-apps/plugin-dialog` (JS) and `tauri-plugin-dialog` (Rust) to enable the native file open dialog.

Replace the free-text path input in the replay tab with:
- A short read-only text field showing the selected filename (or placeholder `No file selected`)
- A `Browse…` button that calls `open({ filters: [{ name: 'Sunshine Log', extensions: ['sun'] }] })`
- On selection, populate `replayPath` state and call `open_replay` automatically

Keep the existing metadata display panel.

---

## Component / File Change Map

| File | Changes |
|---|---|
| `src-tauri/src/pipeline.rs` | Use `SystemTime::now()` for `DataPoint.time_us`; add `get_point_snapshot` method |
| `src-tauri/src/commands.rs` | `start_simulation` → tokio task, emit source_status, wire controls, check stop flag; add `get_channel_snapshot` command; `stop_source` sets stop flag |
| `src-tauri/src/lib.rs` | Add `sim_stop: Arc<AtomicBool>` to `AppState` |
| `src-tauri/Cargo.toml` | Add `tauri-plugin-dialog` |
| `src-tauri/src/main.rs` or `lib.rs` | Register `tauri-plugin-dialog` |
| `package.json` | Add `@tauri-apps/plugin-dialog` |
| `src/hooks/useAppState.ts` | No changes needed |
| `src/components/TopBar.tsx` | Rename `ω` → `SPIN`, `RSSI·B` → `RSSI·BOT` |
| `src/components/DriverStation.tsx` | Replace theta vbar with horizontal slider; add joystick trail; remove CSS transition workaround |
| `src/components/VariableTree.tsx` | Accept `cursorUs` prop; poll `get_channel_snapshot`; display live values |
| `src/components/UPlotCanvas.tsx` | Wire cursor move hook; call `onCursorMove` callback |
| `src/components/GraphPanel.tsx` | Accept + pass `onCursorMove` |
| `src/App.tsx` | Add `cursorUs` state; wire cursor callbacks |
| `src/App.css` | Remove throttle bar CSS transition; add hslider styles |
| `src/types/sunshine.ts` | No changes needed |

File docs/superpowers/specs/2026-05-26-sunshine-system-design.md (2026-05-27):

# Sunshine Combat Robot — System Design Spec
**Date:** 2026-05-26  
**Status:** Approved for implementation planning  
**Schema version:** 1 (initial)

---

## Table of Contents
1. [Overall Architecture & Module Boundaries](#1-overall-architecture--module-boundaries)
2. [IO Layer Data Model](#2-io-layer-data-model)
3. [Brain Firmware](#3-brain-firmware)
4. [Receiver Firmware & Telemetry Protocol](#4-receiver-firmware--telemetry-protocol)
5. [Log File Format](#5-log-file-format)
6. [Host App Architecture](#6-host-app-architecture)
7. [Bringup Plan](#7-bringup-plan)
8. [Deliverable Documents](#8-deliverable-documents)

---

## 1. Overall Architecture & Module Boundaries

### Repository Layout

```
sunshine/
├── sunshine_core/          # Pure C library — NO platform dependencies
│   ├── include/
│   │   └── sunshine_core.h # Public API + all struct definitions
│   ├── src/
│   │   ├── kalman.c        # 2-state Kalman filter (θ, ω)
│   │   ├── derot_filter.c  # Synchronous demodulation + 4th-order LP
│   │   ├── control.c       # DISABLED / TANK / MELTY control logic
│   │   └── brain.c         # sunshine_step() — top-level entry point
│   └── CMakeLists.txt      # Used by PlatformIO; cc crate uses source list directly
├── sunshine_brain/         # PlatformIO ESP32-S3 project
│   ├── include/
│   │   ├── bringup.h       # BRINGUP_LEVEL define + feature flags
│   │   └── config.h        # MAC addresses, pin definitions, tuning constants
│   ├── src/
│   │   ├── main.cpp
│   │   ├── sensors/        # ADXL375 + LIS3MDL SPI drivers
│   │   ├── dshot.cpp       # Bidirectional DShot 600 (DShotRMT_NEO)
│   │   ├── telemetry.cpp   # ESP-NOW TX/RX (Core 0)
│   │   └── nav_control.cpp # 1kHz loop (Core 1)
│   └── platformio.ini      # Multiple bringup environments + production
├── sunshine_receiver/      # PlatformIO ESP32-S3 project
│   ├── include/
│   │   └── config.h        # Brain MAC address, pin definitions
│   ├── src/
│   │   ├── main.cpp
│   │   ├── espnow_rx.cpp
│   │   └── usb_bridge.cpp
│   └── platformio.ini
├── sunshine_app/           # Tauri + React host app
│   ├── src-tauri/
│   │   ├── build.rs        # Compiles sunshine_core via cc crate
│   │   ├── src/
│   │   │   ├── main.rs
│   │   │   ├── ffi.rs          # sunshine_core C bindings + safe wrappers
│   │   │   ├── serial.rs       # USB serial port management
│   │   │   ├── protocol.rs     # USB frame encode/decode
│   │   │   ├── pipeline.rs     # Central data pipeline + ring buffer
│   │   │   ├── replay.rs       # Log file reader + replay engine
│   │   │   ├── simulation.rs   # Brushed DC motor + robot kinematics sim
│   │   │   ├── logging.rs      # .sun file writer
│   │   │   ├── controls.rs     # Latest control state management
│   │   │   └── commands.rs     # All Tauri command handlers
│   │   └── Cargo.toml
│   └── src/                # React frontend
│       ├── components/
│       │   ├── Header.tsx          # Mode buttons + status bar + logging control
│       │   ├── ConnectionPanel.tsx # Live / Replay / Simulation tabs
│       │   ├── GraphPanel.tsx      # uPlot canvas + channel selector
│       │   └── ...
│       └── ...
└── docs/
    ├── ARCHITECTURE.md     # Codebase map for future AI sessions
    ├── BRINGUP.md          # Step-by-step bringup instructions (human-readable)
    ├── TUNING.md           # Kalman + drift tuning guide for humans
    ├── FILTER_MATH.md      # Plain-language explanation of full filter chain
    ├── DEBUGGING.md        # Instructions for sunshine:replay-debug skill
    └── superpowers/specs/  # This document
```

### Data Flow

```
LIVE:       Brain sensors → sunshine_core (on ESP32) → ESP-NOW → Receiver → USB serial → Tauri → React
REPLAY:     .sun file → Tauri (replay.rs) → sunshine_core (FFI) → React
SIMULATION: Tauri (simulation.rs physics) → sunshine_core (FFI) → React
```

### Key Architectural Rules

1. **`sunshine_core` is a pure C island.** No ESP-IDF, no FreeRTOS, no OS calls. Only C99 standard library (math.h, stdint.h, stdbool.h). Compiles identically on ESP32 and desktop.
2. **State is explicit.** No global mutable state above the IO layer. Everything lives in `SunshineState`, passed into and out of `sunshine_step()`.
3. **The IO layer is the contract.** Nothing crosses it except through `SunshineInput` and `SunshineState`.
4. **Safety is structural.** `mode == DISABLED` zeroes DShot outputs unconditionally inside `sunshine_step()`, regardless of any other field. It cannot be bypassed.
5. **New fields are append-only.** Fields may only be added to the end of `SunshineInput`, `SunshineState`, or `SunshineVars`. Never insert, reorder, or resize existing fields. Bump `SUNSHINE_SCHEMA_VERSION` on every change with a comment.
6. **Simulation stays in Rust.** The physics model is only ever called from Tauri. No C simulation code.

---

## 2. IO Layer Data Model

### `SunshineInput` — 1kHz sensor frame (29 bytes packed)

```c
typedef struct __attribute__((packed)) {
    uint32_t time_us;        // Microseconds since boot
    int16_t  accel_x;        // ADXL375 raw counts (49 mg/LSB, ±200g)
                             // IMU mounted 45° to radial — centripetal splits
                             // equally across accel_x and accel_y
    int16_t  accel_y;        // See accel_x. Tangential accel also present during spinup.
    int16_t  accel_z;        // Vertical axis (~+20 counts = 1g at rest)
    int16_t  mag_x;          // LIS3MDL raw counts at ±16 Gauss (0.058 μT/LSB)
    int16_t  mag_y;
    int16_t  mag_z;
    uint16_t erpm_left;      // IEEE 754 float16 bits — left wheel eRPM
    uint16_t erpm_right;     // IEEE 754 float16 bits — right wheel eRPM
    int8_t   rssi;           // ESP-NOW RSSI at brain when receiving control packets (dBm)
    int8_t   ctrl_x;         // Driver input [-127, 127]  (A/D keys)
    int8_t   ctrl_y;         // Driver input [-127, 127]  (W/S keys)
    int8_t   ctrl_theta;     // Driver input [-127, 127]  (left/right arrow, rate)
    uint8_t  ctrl_throttle;  // Driver input [0, 255]     (up/down arrow, accumulates)
    int8_t   batt_offset;    // Battery voltage relative to 7.6V (0.0205 V/LSB, range 5.0–10.2V)
    uint8_t  dshot_left_q;   // DShot command applied on previous tick, quantized [0, 255]
    uint8_t  dshot_right_q;  // Same for right ESC
    uint8_t  mode;           // SUNSHINE_MODE_DISABLED=0, TANK=1, MELTY=2
} SunshineInput;             // sizeof = 29 bytes
```

**Notes:**
- `dshot_left_q`/`dshot_right_q` hold the command from the *previous* tick (what produced this tick's sensor readings). Zero on tick 0.
- At 4000 RPM, centripetal = 196.7g. Across the 45° mount: 139g per axis, well within ±200g. Effective saturation threshold: ~283g ≈ 4800 RPM (above motor max).
- `accel_x`/`accel_y` also carry tangential acceleration during angular acceleration events: `ax = (a_centripetal - a_tangential)/√2`, `ay = (a_centripetal + a_tangential)/√2`.

**Scale constants (in `sunshine_core.h`):**
```c
#define ADXL_SCALE_MS2     (49e-3f * 9.81f)   // m/s² per count
#define MAG_SCALE_UT       0.058f              // μT per count
#define BATT_SCALE_V       0.0205f             // V per count
#define BATT_OFFSET_REF_V  7.6f               // reference voltage
#define IMU_RADIUS_M       0.011f              // 11mm from center
```

---

### `SunshineState` — Filter history (44 bytes packed)

Everything with historical context. Initial conditions needed to deterministically reproduce all future outputs.

```c
typedef struct __attribute__((packed)) {
    // Kalman filter — 2-state [θ (rad), ω (rad/s)]
    float kf_theta;          // Estimated absolute angle (radians, unwrapped)
    float kf_omega;          // Estimated angular velocity (rad/s)
    float kf_P[4];           // 2×2 covariance matrix, row-major [P00,P01,P10,P11]

    // Driver heading offset (accumulated from ctrl_theta)
    float theta_offset;      // rad — rotates the driver's zero-heading reference

    // Synchronous demodulation LP filter states
    // 4th-order Butterworth LP, fc=1 Hz, fs=1kHz, implemented as 2 cascaded biquads
    // State layout per component: [s1_w0, s1_w1, s2_w0, s2_w1]
    float derot_lp_I[4];     // LP state for derotated I component of mag
    float derot_lp_Q[4];     // LP state for derotated Q component of mag
} SunshineState;             // sizeof = 60 bytes
                             // 4+4+16+4+16+16 = 60
                             // (kf_theta + kf_omega + kf_P[4] + theta_offset + derot_lp_I[4] + derot_lp_Q[4])
```

---

### `SunshineVars` — Derived variables (52 bytes, computed each step, never telemetered)

```c
typedef struct __attribute__((packed)) {
    float  omega_from_accel;    // rad/s — sqrt(sqrt(ax²+ay²)*ADXL_SCALE/IMU_RADIUS)
                                //   NOTE: inflated during spinup due to tangential accel
    float  derot_I;             // Derotated + LP-filtered mag I component (μT)
    float  derot_Q;             // Derotated + LP-filtered mag Q component (μT)
    float  mag_angle;           // atan2(derot_Q, derot_I), rad — Earth-field angle
    float  est_theta;           // = kf_theta (rad) — plottable angle estimate
    float  est_omega;           // = kf_omega (rad/s) — plottable omega estimate
    float  dshot_cmd_left;      // Computed DShot value [0, 2000], full precision
    float  dshot_cmd_right;
    float  batt_voltage;        // Actual voltage (V)
    float  erpm_left;           // Decoded from float16
    float  erpm_right;
    float  centripetal_ms2;     // sqrt(ax²+ay²) * ADXL_SCALE, m/s²
    uint8_t led_on;             // 1 when robot angle within ±3° of zero heading
    uint8_t accel_saturated;    // 1 when centripetal_ms2 > 280g equivalent
    uint8_t mag_valid;          // 1 when est_omega > SUNSHINE_MAG_MIN_OMEGA
    uint8_t loop_overrun;       // 1 when 1kHz tick exceeded 1000μs (hardware only)
} SunshineVars;                 // sizeof = 52 bytes
```

---

### C API

```c
// Lifecycle
void     sunshine_state_init(SunshineState *state);
    // Zero-initialises state, sets kf_P to high-uncertainty diagonal

// Main step — call at 1kHz
void     sunshine_step(const SunshineInput *in, SunshineState *state, SunshineVars *vars_out);
    // Pure except for *state mutation. Identical inputs + state → identical output.

// Serialisation (log files use sizeof() directly — structs are packed, no padding)
void     sunshine_input_serialize  (const SunshineInput *in,    uint8_t *buf);
void     sunshine_input_deserialize(const uint8_t *buf,         SunshineInput *in);
void     sunshine_state_serialize  (const SunshineState *state, uint8_t *buf);
void     sunshine_state_deserialize(const uint8_t *buf,         SunshineState *state);

// Schema
uint32_t sunshine_schema_version(void);   // Current: 1. Bump on every struct change.

// Unit conversion utilities
float    sunshine_accel_to_ms2(int16_t raw);    // raw * ADXL_SCALE_MS2
float    sunshine_mag_to_ut   (int16_t raw);    // raw * MAG_SCALE_UT
float    sunshine_batt_to_v   (int8_t  off);    // BATT_OFFSET_REF_V + off * BATT_SCALE_V
float    sunshine_f16_to_f32  (uint16_t half);
uint16_t sunshine_f32_to_f16  (float f);
```

---

### Schema Versioning

Log file header stores `schema_version`, `sizeof_input`, `sizeof_state`, `sizeof_vars`. When reading old files:
- `sizeof < current`: missing trailing fields default to zero/false
- `sizeof > current`: extra bytes skipped with `fseek`

No converter functions needed — the append-only rule handles it.

---

## 3. Brain Firmware

### Core Assignment

```
Core 0 — Telemetry task (FreeRTOS, priority 5)
  • ESP-NOW TX: 50 Hz state+inputs frames to receiver
  • ESP-NOW RX callback: stores latest control inputs + RSSI behind a mutex
  • Drains ring buffer produced by Core 1

Core 1 — Nav+Control task (FreeRTOS, priority 10, pinned)
  • 1kHz hard real-time loop
  • Pushes (SunshineInput, SunshineState) snapshots to ring buffer
  • Never blocks on telemetry
```

Ring buffer: 40 entries × (29+60) bytes = 3.6 KB. Absorbs 40ms of Core 0 scheduling jitter. Oldest entry overwritten if full — Core 1 never blocks.

### SPI Bus Assignment

| Bus | Peripheral | SCK | MOSI | MISO | CS |
|-----|---|-----|---|---|----|
| `FSPI` | ADXL375 (Adafruit library) | IO12 | IO11 | IO13 | IO10 |
| `HSPI` | LIS3MDL (Adafruit library) | IO16 | IO15 | IO17 | IO18 |

- ADXL375: ODR 1600 Hz, full-resolution mode, polled (no interrupt needed at 1kHz poll rate)
- LIS3MDL: ODR 1000 Hz (`LIS3MDL_DATARATE_1000_HZ`), ±16 Gauss, continuous conversion
- DShot: IO4 (left), IO5 (right) — bidirectional DShot 600 via DShotRMT_NEO, pull-ups on PCB
- Battery ADC: IO39, `V_bat = analogRead(39) * (3.3/4095.0) * 3.0`

### 1kHz Loop Structure

```
Every 1000 μs (enforced by busy-wait on micros()):

  t_start = micros()

  1. read_sensors()          → fill accel, mag, batt_offset, erpm fields in input
  2. copy_control_inputs()   → acquire mutex, copy ctrl_*, mode, rssi
  3. carry_prev_dshot()      → input.dshot_left_q  = quantize(prev_vars.dshot_cmd_left)
                               input.dshot_right_q = quantize(prev_vars.dshot_cmd_right)
  4. input.time_us = t_start

  5. sunshine_step(&input, &state, &vars)

  6. apply_outputs()
       send_dshot(LEFT,  vars.dshot_cmd_left)
       send_dshot(RIGHT, vars.dshot_cmd_right)
       digitalWrite(LED_PIN, vars.led_on)

  7. push_to_ring_buffer(&input, &state)

  8. elapsed = micros() - t_start
     if elapsed > 1000: overrun_count++; Serial.printf("OVERRUN %uus\n", elapsed)
     else: spin until t_start + 1000
```

### Kalman Filter

**State:** `x = [θ, ω]ᵀ`, dt = 0.001 s

**Predict (every tick):**
```
F = [[1, dt], [0, 1]]
x = F·x
P = F·P·Fᵀ + Q
```

**Update — accelerometer (every tick, skip if accel_saturated):**
```
centripetal = sqrt(accel_x² + accel_y²) * ADXL_SCALE_MS2
omega_meas  = sqrt(centripetal / IMU_RADIUS_M)
H = [0, 1];  innovation = omega_meas − H·x
S = H·P·Hᵀ + R_ACCEL;  K = P·Hᵀ / S
x += K·innovation;  P = (I − K·H)·P
```

**Update — magnetometer (only when mag_valid: est_omega > 4π rad/s ≈ 120 RPM):**
```
theta_meas = vars->mag_angle    (from synchronous demodulation output)
H = [1, 0];  innovation = wrap_to_pi(theta_meas − H·x)
S = H·P·Hᵀ + R_MAG;  K = P·Hᵀ / S
x += K·innovation;  P = (I − K·H)·P
```

**Tuning constants (in `sunshine_core.h`, documented for human tuning):**
```c
#define KF_Q_THETA   1e-6f   // Process noise: angle (rad²/step) — increase if angle drifts
#define KF_Q_OMEGA   1e-3f   // Process noise: omega (rad²/s²/step) — increase for faster tracking
#define KF_R_ACCEL   0.5f    // Accel noise (rad²/s²) — increase to reduce accel influence
#define KF_R_MAG     0.1f    // Mag noise (rad²) — increase to reduce mag influence
```

### Synchronous Demodulation (Magnetometer Filter)

Earth's field oscillates at body rotation frequency in the IMU frame. Derotating by the current Kalman theta shifts it to DC; a fixed LP filter then rejects motor/ESC offsets (which appear at f_rot in the derotated frame).

```c
// Derotate using current theta estimate
float theta = state->kf_theta + state->theta_offset;
float I_raw = input->mag_x * cosf(theta) + input->mag_y * sinf(theta);
float Q_raw = -input->mag_x * sinf(theta) + input->mag_y * cosf(theta);

// Apply 4th-order Butterworth LP (two cascaded biquad sections), fc=1 Hz, fs=1kHz
float I_filt = biquad_cascade(I_raw, state->derot_lp_I);
float Q_filt = biquad_cascade(Q_raw, state->derot_lp_Q);

vars->derot_I   = I_filt;
vars->derot_Q   = Q_filt;
vars->mag_angle = atan2f(Q_filt, I_filt);
```

**4th-order Butterworth LP coefficients** (fc=1 Hz, fs=1000 Hz, two cascaded Direct Form II biquads):
```c
// Section 1
#define LP4_S1_B0  9.886e-7f
#define LP4_S1_B1  1.977e-6f
#define LP4_S1_B2  9.886e-7f
#define LP4_S1_A1 -1.99112f
#define LP4_S1_A2  0.99115f
// Section 2
#define LP4_S2_B0  9.886e-7f
#define LP4_S2_B1  1.977e-6f
#define LP4_S2_B2  9.886e-7f
#define LP4_S2_A1 -1.99679f
#define LP4_S2_A2  0.99682f
```

**Minimum usable speed:** 120 RPM (4π rad/s). At this speed the motor offsets (at f_rot = 2 Hz) are attenuated ~40 dB below the Earth's field signal. Below this threshold Kalman angle update is skipped; filter continues running to maintain state.

**Effect during spinup:** `omega_from_accel` reads high (tangential acceleration adds to centripetal magnitude). Visible in graphs as divergence between `omega_from_accel` and `est_omega` during spin-up transients — this is expected and useful for filter tuning.

### Control Modes

**DISABLED:** `sunshine_step()` unconditionally sets `dshot_cmd_left = dshot_cmd_right = 0`. Structural — not a conditional check.

**TANK:**
```c
float fwd  = (ctrl_throttle / 127.5f) - 1.0f;    // −1..+1
float turn = ctrl_x / 127.0f;
dshot_cmd_left  = map_to_dshot(clampf(fwd + turn, -1, 1));
dshot_cmd_right = map_to_dshot(clampf(fwd - turn, -1, 1));
// map_to_dshot: ESC-specific, AM32 3D mode, finalised at Bringup Level 2
```

**MELTY:**
```c
// Heading offset (rate control)
state->theta_offset += (ctrl_theta / 127.0f) * THETA_RATE_RADS * dt;

// Base spin throttle (open-loop)
float base = (ctrl_throttle / 255.0f) * MAX_DSHOT_SPIN;

// Trapezoidal translation wave
float drive_dir = atan2f(ctrl_y, ctrl_x);
float drive_mag = sqrtf(ctrl_x*ctrl_x + ctrl_y*ctrl_y) / 127.0f;
float phase     = wrap_to_pi(state->kf_theta + state->theta_offset - drive_dir);
float diff      = trapezoid(phase, DRIFT_PULSE_WIDTH, DRIFT_RAMP_WIDTH)
                  * drive_mag * DRIFT_AMPLITUDE * base;

dshot_cmd_left  = clampf(base + diff, 0, MAX_DSHOT);
dshot_cmd_right = clampf(base - diff, 0, MAX_DSHOT);
```

**LED:** On when `|wrap_to_pi(kf_theta + theta_offset)| < 0.0524 rad` (±3°).

**Tuning constants:**
```c
#define DRIFT_PULSE_WIDTH   0.25f   // fraction of rotation at peak differential
#define DRIFT_RAMP_WIDTH    0.10f   // fraction for linear ramp transition
#define DRIFT_AMPLITUDE     0.40f   // max differential as fraction of base throttle
#define THETA_RATE_RADS     3.14f   // rad/s per full ctrl_theta deflection
#define MAX_DSHOT_SPIN      1500.0f // max DShot value used for body spin
```

### Error Handling & LED Patterns

On startup, each sensor `begin()` is checked. On failure:

| Blink count | Fault |
|---|---|
| 1 | ADXL375 init failed |
| 2 | LIS3MDL init failed |
| 3 | DShot arming failed |
| 4+ | Multiple failures |

Pattern: N fast blinks (50ms on/off) → 1s off → repeat. Error also printed to USB serial at 1 Hz continuously — plug in USB any time to see the fault.

### Bringup Environments (platformio.ini)

```ini
[env:bringup_1_sensors]     build_flags = -DBRINGUP_LEVEL=1
[env:bringup_2_dshot]       build_flags = -DBRINGUP_LEVEL=2
[env:bringup_3_telemetry]   build_flags = -DBRINGUP_LEVEL=3
[env:bringup_4_navigation]  build_flags = -DBRINGUP_LEVEL=4
[env:production]            build_flags = -DBRINGUP_LEVEL=0
```

---

## 4. Receiver Firmware & Telemetry Protocol

### Task Structure

```
Core 0 — ESP-NOW RX callback
  • Validates incoming brain telemetry frames
  • Writes to a double-buffer (2 entries sufficient at 50 Hz)
  • Records receiver-side RSSI from ESP-NOW callback metadata

Core 1 — USB bridge + 500 Hz ESP-NOW TX
  • USB RX: any incoming frame from host resets `last_host_rx_us` watchdog;
            CTRL_PACKET updates `latest_ctrl` struct (mutex-protected)
  • USB TX: forwards brain telemetry frames to host
  • esp_timer @ 500 Hz: reads `latest_ctrl`, sends to brain via ESP-NOW
            If micros() - last_host_rx_us > 3,000,000: forces mode=DISABLED first
  • Heartbeat TX: 10 Hz STATUS packet to host
```

The 500 Hz ESP-NOW TX rate is generated entirely by the receiver's `esp_timer` — it does not depend on the host sending at any particular rate. The host can send at any rate; the receiver always rebroadcasts at 500 Hz with the latest known state.

### ESP-NOW Configuration

- Both devices: max TX power (`esp_wifi_set_max_tx_power(84)`)
- No ACK, no retransmit on either channel
- MAC addresses hardcoded in `config.h` on both devices
- Fixed channel 1 (no auto-switching)
- ESP-NOW v2.0 required — `platform = espressif32 @ >=6.0.0` in both `platformio.ini`
  > **Platform status (2026-05-26):** The pioarduino `stable` URL currently fails to install (`MissingPackageManifestError` on `framework-arduinoespressif32-libs`). The receiver was built against `espressif32@6.0.0` (IDF 4.4) as a workaround; the brain's pioarduino URL needs the same fix. IDF 4.4 uses a different `esp_now_recv_cb_t` signature (no `esp_now_recv_info_t`), so receiver-side RSSI is unavailable from the callback — `espnow_rx_update_rssi()` is a hook for a promiscuous sniffer. Once pioarduino is fixed, both projects should switch to the URL for full IDF 5.x support.
- Both brain and receiver are ESP32-S3 → v2.0 compatible, 1470-byte payload available
- 643-byte telemetry packet is well under the 1470-byte v2.0 limit

### Packet Formats

**ESP-NOW: Brain → Receiver (50 Hz, 635 bytes)**
```
Offset  Size  Field
0       2     frame_id (uint16 LE, monotonic)
2       1     type = 0x01
3       60    SunshineState (packed)
63      580   SunshineInput[20] (20 × 29 bytes, packed)
Total: 643 bytes
```

**ESP-NOW: Receiver → Brain (500 Hz, 8 bytes)**
```
Offset  Size  Field
0       2     seq_id (uint16 LE)
2       1     type = 0x02
3       1     mode
4       1     ctrl_x
5       1     ctrl_y
6       1     ctrl_theta
7       1     ctrl_throttle
Total: 8 bytes
```

### USB Serial Protocol (Receiver ↔ Host)

All frames: `[0xAA] [type: 1B] [payload_len: 2B LE] [payload: NB] [checksum: 1B XOR of payload]`

| Type | Direction | Payload | Rate |
|---|---|---|---|
| `0x01` TELEM_FRAME | Receiver→Host | Full ESP-NOW telemetry payload (635 B) | 50 Hz |
| `0x02` CTRL_PACKET | Host→Receiver | `mode, ctrl_x, ctrl_y, ctrl_theta, ctrl_throttle` (5 B) | As sent by host |
| `0x03` STATUS | Both | `status_code (1B) + ascii message (≤32B)` | On event |
| `0x04` HEARTBEAT | Both | `timestamp_ms (4B)` | 10 Hz |
| `0x05` RX_RSSI | Receiver→Host | `rssi (int8, receiver-side reading of brain signal)` | 10 Hz |

**Status codes:**
```
0x00  OK
0x01  BRAIN_CONNECTED
0x02  BRAIN_DISCONNECTED    (>200ms since last brain frame — 10 missed at 50 Hz)
0x03  USB_LOGGING_STOPPED
0x04  INIT_ERROR
```

### Safety Watchdog Chain

```
Host app sends any USB packet → resets receiver's last_host_rx_us
    ↓ (if silent > 3 seconds)
Receiver forces mode=DISABLED in latest_ctrl (500 Hz timer callback)
    ↓
500 Hz timer sends DISABLED to brain via ESP-NOW
    ↓ (if brain receives no control packet for > 500ms)
Brain watchdog forces input.mode = DISABLED before sunshine_step()
    ↓
sunshine_step() DISABLED path → zero DShot outputs (structural)
```

Three independent watchdogs. Any broken link disables the robot within ≤3.5 seconds.

### Reconnect Handling

| Event | Brain | Receiver | Host |
|---|---|---|---|
| Receiver USB unplugged | Continues; watchdog runs | Restarts on replug | Detects disconnect; pauses log |
| Receiver USB replugged | No effect | Sends BRAIN_CONNECTED if frames arriving | Opens **new** log file |
| Brain loses power | — | 10 missed frames → BRAIN_DISCONNECTED | Shows disconnected |
| Brain reconnects | Rejoins ESP-NOW (MAC hardcoded, no handshake) | Resumes forwarding | Opens new log file |

All multi-byte values: little-endian throughout (ESP32-S3 and macOS/ARM both LE).

---

## 5. Log File Format

### File Naming & Lifecycle

**Format:** `YYYY-MM-DD_HH-MM-SS[_label].sun`

- Label optional, set from host app UI (e.g. `match_1`, `practice_3`)
- **New file on every fresh connection** — never appended to
- Frames flushed to disk every 10 frames (200ms) — worst-case 200ms lost on crash
- `logging_complete` flag set on clean close
- Logging can be toggled from host app at any time; re-enabling creates a new file

### File Header (93 bytes)

```
Offset  Size  Field
0       5     magic = "SHINE"
5       2     file_format_version (uint16 LE) = 1
7       2     header_size (uint16 LE) = 93  — reader skips to here for first frame
9       4     schema_version (uint32 LE)
13      2     sizeof_input (uint16 LE)
15      2     sizeof_state (uint16 LE)
17      2     sizeof_vars  (uint16 LE)
19      8     created_at_ms (uint64 LE, Unix ms)
27      1     source: 0=live, 1=replay, 2=simulation
28      1     flags: bit0=logging_complete, bits1-7 reserved
29      64    label (null-terminated UTF-8, zero-padded)
Total: 93 bytes
```

### Frame Structure (~681 bytes at schema v1, 50 Hz)

```
Offset          Size          Field
0               4             frame_id (uint32 LE, monotonic — gaps = dropped telemetry)
4               1             frame_flags (bit0=vars_valid, bits1-7 reserved)
5               sizeof_state  SunshineState (state at START of frame, before any inputs)
5+S             sizeof_input × 20  SunshineInput[20]
5+S+20I         sizeof_vars   SunshineVars (computed after all 20 steps — 50 Hz snapshot)
```

At schema v1: 5 + 60 + 580 + 52 = **697 bytes/frame**  
At 50 Hz: ~35 KB/s | 5-min match: ~10.5 MB | 30-min session: ~63 MB

### Backwards Compatibility

```rust
fn read_struct<T: Default + AsBytesMut>(file: &mut File, file_size: usize) -> T {
    let mut obj = T::default();
    let read_bytes = file_size.min(size_of::<T>());
    file.read_exact(&mut obj.as_bytes_mut()[..read_bytes])?;
    if file_size > size_of::<T>() {
        file.seek(SeekFrom::Current((file_size - size_of::<T>()) as i64))?;
    }
    obj
}
```

### Real vs Replayed Data

| Data | Source | Resolution | In .sun file |
|---|---|---|---|
| Real inputs | Robot telemetry | 1kHz | ✓ (20 per frame) |
| Real state | Robot telemetry | 50 Hz | ✓ (1 per frame) |
| Real vars | Computed at log time | 50 Hz | ✓ (1 per frame) |
| Replayed state | `sunshine_step()` replay | 1kHz | ✗ (computed live) |
| Replayed vars | `sunshine_step()` replay | 1kHz | ✗ (computed live) |

Graphing shows Real and Replayed as separate selectable series. Real is 50 Hz (thin/dotted), Replayed is 1kHz (solid). DShot: Real = `dshot_left_q` (quantized input), Replayed = `dshot_cmd_left` (full precision vars).

---

## 6. Host App Architecture

### Rust Backend Modules

```
src-tauri/src/
├── main.rs        — Tauri setup, app state init
├── ffi.rs         — sunshine_core C bindings + safe wrappers (only unsafe block)
├── serial.rs      — Serial port management + reconnect loop (serialport crate)
├── protocol.rs    — USB serial frame encode/decode
├── pipeline.rs    — Central data pipeline: owns ring buffer, drives live/replay/sim
├── replay.rs      — .sun file reader + replay loop
├── simulation.rs  — Brushed DC motor + robot kinematics physics model
├── logging.rs     — .sun file writer
├── controls.rs    — Latest control state + serialisation
└── commands.rs    — All Tauri command handlers (JS-callable)
```

### FFI Layer

`build.rs` compiles `sunshine_core/` via the `cc` crate. Rust structs use `#[repr(C, packed)]` to exactly match C layout.

```rust
extern "C" {
    fn sunshine_step(i: *const SunshineInput, s: *mut SunshineState, v: *mut SunshineVars);
    fn sunshine_state_init(s: *mut SunshineState);
    fn sunshine_schema_version() -> u32;
    fn sunshine_f16_to_f32(half: u16) -> f32;
    fn sunshine_f32_to_f16(f: f32) -> u16;
}

/// Safe wrapper — the only place `unsafe` appears for sunshine_core
pub fn brain_step(input: &SunshineInput, state: &mut SunshineState) -> SunshineVars { ... }
```

### Simulation Engine (`simulation.rs`)

Pure Rust, 1kHz driven by `pipeline.rs`. Produces `SunshineInput` each tick; DShot outputs from `SunshineVars` feed back as motor commands.

**Motor model (brushed DC, per wheel):**
```
KV      = 1100.0 RPM/V
Kt      = 60 / (2π × KV)  ≈ 8.68e-3 N·m/A    (standard brushless formula, SI)
R_phase = 0.075 Ω

back_emf = wheel_omega / (KV × 2π/60)
V_motor  = dshot_fraction × V_terminal
i_motor  = (V_motor - back_emf) / R_phase
torque   = Kt × i_motor
```

**Battery model (internal resistance only — no SOC drain):**
```
V_NOMINAL  = 8.4 V  (configurable constant)
R_INTERNAL = 8 mΩ
V_terminal = V_NOMINAL - (i_left + i_right) × R_INTERNAL
```

**Body dynamics:**
```
wheel_omega = body_omega × WHEEL_CENTER_R / WHEEL_RADIUS
           = body_omega × 40.5mm / 22mm

torque_body = (torque_left + torque_right) × WHEEL_CENTER_R / WHEEL_RADIUS
alpha       = torque_body / MOI          [MOI = 1.214e-3 kg·m²]
body_omega += alpha × dt
body_angle += body_omega × dt
```

**Sensor models:**
```
// Centripetal + tangential (tangential present during spinup)
a_centripetal = body_omega² × IMU_RADIUS
a_tangential  = alpha × IMU_RADIUS
ax = (a_centripetal - a_tangential) / √2      // 45° mount
ay = (a_centripetal + a_tangential) / √2
az = 9.81 m/s²  (gravity)
input.accel_{x,y,z} = (a{x,y,z} / ADXL_SCALE_MS2) as i16

// Magnetometer: ideal Earth field (50 μT, fixed direction φ_earth)
input.mag_x = (EARTH_FIELD_UT × cos(φ_earth - body_angle) / MAG_SCALE_UT) as i16
input.mag_y = (EARTH_FIELD_UT × sin(φ_earth - body_angle) / MAG_SCALE_UT) as i16
input.mag_z = 0

// Battery
input.batt_offset = round((V_terminal - 7.6) / 0.0205) as i8
```

Physical constants (in `simulation.rs`, easily editable):
```rust
const KV: f64           = 1100.0;
const R_PHASE: f64      = 0.075;
const V_NOMINAL: f64    = 8.4;
const R_INTERNAL: f64   = 0.008;
const WHEEL_RADIUS: f64 = 0.022;
const WHEEL_CENTER: f64 = 0.0405;
const MOI: f64          = 1.214e-3;
const IMU_RADIUS: f64   = 0.011;
const EARTH_FIELD: f64  = 50.0;   // μT
```

### Data Pipeline (`pipeline.rs`)

Ring buffer: last 120 seconds × 20 ticks/frame = 6000 frames × ~(29×20 + 44 + 52) = ~4 MB. Held in Rust, never pushed to frontend in bulk.

Three source modes share identical post-`brain_step()` code:

```
LIVE:       serial → protocol decode → TelemetryFrame{state, inputs[20]}
            → brain_step() × 20 → Vec<SunshineVars>
            → push 20 (input, vars) + state to ring buffer
            → logging.write_frame()  → emit live_update event

REPLAY:     replay.rs reads .sun frames → same brain_step() × 20 path
            (controllable speed: 1×, 5×, 10×, max)

SIMULATION: simulation.tick() → SunshineInput
            → brain_step() → SunshineVars
            → simulation.apply(vars.dshot_cmd_left, vars.dshot_cmd_right)
            → ring buffer + optional logging + events
```

### Graph Data Architecture

**Pull-based.** Frontend calls `get_graph_data` when viewport changes:

```
get_graph_data(
    channel:    String,   // e.g. "vars.est_theta", "inputs.accel_x"
    start_us:   u64,
    end_us:     u64,
    max_points: u32,      // viewport pixel width
    series:     Series,   // Real | Replayed
) → Vec<(u64, f32)>
```

Backend decimates using **min/max envelope** (preserves peaks). Result is at most `max_points` pairs. Called on: new data arriving (append latest to visible window) and user zoom/pan.

**Library:** uPlot (canvas-based, handles 1M+ points, ~40KB).

**Aesthetics:** Match the mockup exactly — dark theme, colored signal lines, minimal grid, units on y-axis labels, thin/dotted Real series vs solid Replayed series, Ctrl+scroll to zoom, scroll to pan. Extract CSS variables from the mockup HTML and apply directly to the Tauri WebView.

### Driver Controls

```typescript
// Target values from keys
onKeyDown('w') => target.y = 127;    onKeyUp('w') => target.y = 0
onKeyDown('s') => target.y = -127;   onKeyUp('s') => target.y = 0
onKeyDown('a') => target.x = -127;   onKeyUp('a') => target.x = 0
onKeyDown('d') => target.x = 127;    onKeyUp('d') => target.x = 0
onKeyDown('ArrowLeft')  => target.theta = -127;  onKeyUp => target.theta = 0
onKeyDown('ArrowRight') => target.theta = 127;   onKeyUp => target.theta = 0
onKeyDown('ArrowUp')   => throttle_delta = +THROTTLE_RATE
onKeyDown('ArrowDown') => throttle_delta = -THROTTLE_RATE

// Heavy LP filter at 60 Hz (requestAnimationFrame)
const ALPHA = 0.03   // ~1.8 Hz effective bandwidth
filtered.x     += ALPHA * (target.x     - filtered.x)
filtered.y     += ALPHA * (target.y     - filtered.y)
filtered.theta += ALPHA * (target.theta - filtered.theta)
filtered.throttle = clamp(filtered.throttle + throttle_delta, 0, 255)

// Send to Rust at ~30 Hz (every 2nd animation frame)
invoke('set_controls', { ...filtered })
```

Throttle resets to 0 on mode=DISABLED or source disconnect.

### Tauri Commands & Events

**Commands (JS → Rust):**
```
list_serial_ports() → Vec<String>
connect_serial(port) | disconnect_serial()
open_replay(path) → LogMetadata
start_simulation() | stop_source()
set_mode(mode: u8)
set_controls(x, y, theta, throttle)
enable_logging(label) → file_path | disable_logging()
get_graph_data(...) → Vec<(u64, f32)>
```

**Events (Rust → JS, 50 Hz):**
```
live_update  { est_theta, est_omega, batt_voltage, rssi, mode,
               brain_connected, receiver_connected, frame_id,
               loop_overrun_count, bandwidth_bps }
source_status { kind: Live|Replay|Sim|Disconnected, detail }
log_status    { active, path, frame_count }
error         { code, message }
```

### React Component Structure

```
App
├── Header
│   ├── ModeButtons        (DISABLED=red / TANK=yellow / MELTY=green, large)
│   ├── StatusBar          (RSSI, bandwidth, brain/receiver status, battery indicator)
│   └── LoggingControl     (toggle + label input)
├── ConnectionPanel
│   ├── LiveTab            (port selector, connect, receiver/brain status)
│   ├── ReplayTab          (file picker, play/pause, speed, scrub bar, file metadata)
│   └── SimulationTab      (start/stop, read-only sim parameters)
├── GraphPanel
│   ├── ChannelSelector    (grouped: Inputs / State / Variables; Real vs Replayed toggle)
│   └── uPlotCanvas
└── (keyboard listener on window)
```

Battery indicator colours (2S LiPo): ≥8.0V green, 7.4–8.0V yellow, 7.0–7.4V orange, <7.0V red (blinking).

---

## 7. Bringup Plan

Full step-by-step instructions with expected outputs and pass/fail criteria are in `BRINGUP.md`. This section is the structural overview.

### Level 1 — Low-level Sensors

**Goal:** All sensors init and read correctly over USB serial.  
**Setup:** Board powered via USB, no ESCs connected.  
**Env:** `bringup_1_sensors`  
**Output:** Labeled CSV at 100 Hz on USB serial (Arduino Serial Plotter compatible).

| Sensor | Expected at rest |
|---|---|
| ADXL375 | `accel_z ≈ +20` counts (1g); shake → all axes respond |
| LIS3MDL | Magnitude ≈ 860 counts (50 μT); rotate → `mag_x/y` traces circle |
| ADC | Maps to actual battery voltage ±0.1V (verify with multimeter) |

Pass: all sensors init, no LED error pattern, values sensible.

### Level 2 — DShot & ESC

**Goal:** Bidirectional DShot 600 working, eRPM telemetry readable.  
**Setup:** ESCs connected. **Props OFF.** AM32 pre-configured for 3D mode + correct directions.  
**Env:** `bringup_2_dshot`  
**Interface:** Simple USB serial command: `l <0-2000>`, `r <0-2000>`, `s`, `t` (print eRPM).

Pass: ESCs arm, both directions spin, eRPM matches expected RPM, success rate >90%.

### Level 3 — Telemetry Link

**Goal:** Full brain→receiver→host pipeline live in host app.  
**Setup:** Brain + receiver powered, host app running. Props OFF.  
**Env:** `bringup_3_telemetry` (motor outputs zeroed)

Checklist:
1. Host app: connect to receiver serial port → both status indicators green
2. Plot `inputs.accel_z` → stable ~1g; shake board → spikes visible
3. Rotate board → `inputs.mag_x/y` sinusoid visible
4. Check `inputs.rssi` → plausible negative dBm value
5. Press W key → `inputs.ctrl_y` ramps up (LP filter visible)
6. Walk receiver away → RSSI decreases
7. 2-minute stability test: no `BRAIN_DISCONNECTED` events, `frame_id` gaps rare

Pass: all of the above, log file contains clean data.

### Level 4 — Navigation Tuning

**Goal:** Kalman filter tuned, LED appears stationary when spinning, TANK mode working.  
**Setup:** Full robot, props OFF initially.  
**Env:** `bringup_4_navigation`

Tuning steps (detailed in `TUNING.md`):
1. Spin slowly → verify `omega_from_accel` responds; see spinup transient (expected)
2. Spin > 300 RPM → verify `derot_I`/`derot_Q` are near-constant (DC)
3. Tune `KF_R_ACCEL`, `KF_Q_OMEGA` for omega tracking quality
4. Tune `KF_R_MAG`, `KF_Q_THETA` for angle tracking quality
5. Verify LED appears stationary at a fixed heading

Pass: LED stationary ±5° at 500+ RPM; `est_theta` tracks with <5° RMS error; no drift over 30s.

### Level 5 — Drift Tuning (Full MELTY)

**Goal:** Robot translates reliably in commanded direction while spinning.  
**Setup:** Open floor, props ON, safe area.  
**Env:** `production`

1. Confirm LED is stationary (heading locked) — if not, return to Level 4
2. Apply small Y+ at low throttle → robot should drift forward
3. Tune `DRIFT_AMPLITUDE`, `DRIFT_PULSE_WIDTH`, `DRIFT_RAMP_WIDTH` per `TUNING.md`

Pass: translates in commanded direction at ≥3 of 4 compass points; no wheel slip; LED stationary during translation.

---

## 8. Deliverable Documents

| File | Contents |
|---|---|
| `docs/ARCHITECTURE.md` | Codebase map for future AI sessions: module purposes, file locations, key interfaces, the append-only rule, schema versioning |
| `docs/BRINGUP.md` | Step-by-step human instructions for all 5 bringup levels with expected outputs and troubleshooting |
| `docs/TUNING.md` | Human-readable Kalman tuning guide + drift profile tuning with parameter tables |
| `docs/FILTER_MATH.md` | Plain-language + diagrams: centripetal→omega, sync demodulation, IQ low-pass, Kalman predict/update |
| `docs/DEBUGGING.md` | Instructions for the `sunshine:replay-debug` Claude skill |
| `docs/superpowers/specs/` | This document |

---

## Physical Constants Reference

| Parameter | Value | Source |
|---|---|---|
| Motor KV | 1100 RPM/V | Spec |
| Motor Kt | 60/(2π×1100) ≈ 8.68 mN·m/A | Calculated |
| Phase resistance | 75 mΩ | Spec |
| Wheel radius | 22 mm | Spec |
| Wheel center from axis | 40.5 mm | Spec |
| Robot MoI | 1213859 g·mm² = 1.214×10⁻³ kg·m² | Spec |
| IMU offset from center | 11 mm | PCB |
| IMU rotation | 45° to radial direction | PCB |
| Battery | 2S 650mAh 120C LiPo | Spec |
| Battery internal resistance | 8 mΩ | Estimated |
| Battery nominal voltage | 8.4V (full charge) | 2S LiPo |
| Max body RPM (estimated) | ~4000 RPM | Calculated (79.7% motor no-load) |
| Max centripetal @ IMU | 196.7g @ 4000 RPM | Calculated |
| Effective saturation RPM | ~4800 RPM | Calculated (45° mount) |
| Butterworth LP fc | 1 Hz | Design |
| Min usable mag speed | 120 RPM (4π rad/s) | Design |
| Earth magnetic field | 50 μT | Typical |

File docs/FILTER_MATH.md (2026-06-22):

# Filter Chain — Math and Intuition

Plain-language explanation of the full signal processing chain in `sunshine_core`. All the math that goes from raw sensor counts to estimated angle and angular velocity.

---

## Overview

The robot spins. We want to know:
1. **How fast is it spinning?** → angular velocity ω (rad/s)
2. **What angle is it at right now?** → absolute angle θ (rad)

We have three sensors:
- **Accelerometer (ADXL375):** measures centripetal force → tells us ω (indirectly)
- **Magnetometer (LIS3MDL):** measures Earth's magnetic field → tells us θ (indirectly, after filtering)
- **DShot eRPM:** tells us wheel speed, but that's used for control feedback, not navigation

The processing pipeline:

```
Raw accel counts → centripetal_ms2 → omega_from_accel ──────────────────────────┐
                                                                                  ↓
                                                                          Kalman filter
                                                                                  ↑
Raw mag counts → derotate by θ estimate → I/Q components → 4th-order LP → mag_angle ┘
```

---

## Step 1: Centripetal Force → Angular Velocity

### Why centripetal gives us ω

When an object moves in a circle, it experiences centripetal acceleration directed toward the center:

```
a_centripetal = ω² × r
```

The IMU is mounted 11 mm from the robot's spin axis (`IMU_RADIUS_M = 0.011 m`). At angular velocity ω rad/s, the centripetal acceleration is `ω² × 0.011 m/s²`.

Rearranging: `ω = sqrt(a_centripetal / r)`

### The 45° mount

The IMU is physically rotated 45° relative to the radial direction. At 45°, centripetal acceleration (pointing inward radially) projects equally onto both `accel_x` and `accel_y`. This is intentional — it keeps both axes well within the ±200g range of the ADXL375 up to ~4800 RPM.

Raw centripetal magnitude:
```c
centripetal_ms2 = sqrt(accel_x² + accel_y²) * ADXL_SCALE_MS2
               = sqrt(accel_x² + accel_y²) * (49e-3 * 9.81)
```

Then:
```c
omega_from_accel = sqrt(centripetal_ms2 / IMU_RADIUS_M)
```

### The spin-up problem

During angular acceleration (spin-up or spin-down), the robot also produces **tangential acceleration** at the IMU. This adds to the centripetal vector:

```
ax = (a_centripetal - a_tangential) / sqrt(2)   (45° mount geometry)
ay = (a_centripetal + a_tangential) / sqrt(2)
```

When computing `sqrt(ax² + ay²)`, the tangential component doesn't cancel cleanly — it inflates the magnitude:

```
sqrt(ax² + ay²) = sqrt(a_centripetal² + a_tangential²) / sqrt(2) × sqrt(2)
                = sqrt(a_centripetal² + a_tangential²)
```

So during spin-up, `omega_from_accel` reads higher than true ω. This is the divergence you see in the graphs at spin-up. It's expected and harmless — the Kalman filter's covariance tracking limits how far the estimate can be pulled by the inflated reading.

### Saturation

At high speeds (> ~280g centripetal ≈ 4800 RPM), the ADXL375's ±200g range saturates. The code detects this:

```c
accel_saturated = centripetal_ms2 > (280.0f * 9.81f)
```

When saturated, the accel Kalman update is skipped entirely. The estimate coasts on the mag update and the model prediction.

---

## Step 2: Open-Loop Absolute Heading (Magnetometer)

### The problem: Earth's field rotates in the IMU frame

Earth's magnetic field is a fixed vector in the lab frame. As the robot spins, that vector appears to rotate in the IMU's frame of reference. The magnetometer reads a sinusoidal oscillation at exactly the body rotation frequency.

In the IMU frame, if the robot is at angle θ, the Earth field (amplitude B, direction φ_earth) reads:

```
mag_x = B × cos(φ_earth - θ)
mag_y = B × sin(φ_earth - θ)
```

So mag_x and mag_y oscillate at the rotation frequency. We want to extract φ_earth − θ (i.e., the absolute angle θ, given φ_earth is constant).

### The solution: a spin-tracking band-pass, then atan2 of the two axes

Three things sit in the magnetometer signal: (a) the **Earth field**, at the spin
frequency `f_rot`; (b) a **body-fixed DC offset** (hard-iron + the roughly
constant average ESC current — DC because it doesn't rotate with the body); and
(c) **high-frequency tones** from the LIS3MDL's 1 kHz low-power-mode sampling — a
strong one at `f_s/6 ≈ 167 Hz`, measured ~7 µT. (ESC *switching* is far higher,
kHz, and irrelevant — there is no spin-frequency ESC content.)

To isolate the Earth sine we run a **2nd-order RBJ band-pass** (Robert
Bristow-Johnson's "audio EQ cookbook" biquad) on each axis, **centred on the spin
frequency** taken from `omega_from_accel` — the accelerometer rate, which is
**independent of the heading estimate** (the OPEN-LOOP note below explains why the
centre must come from the accel and *not* from `kf_omega`):

```c
float fc    = omega_from_accel / (2π);      // band centre = accel spin freq (Hz)
float w0    = 2π·fc / 1000;                 // fs = 1 kHz
float alpha = sin(w0) / (2·MAG_BP_Q);       // MAG_BP_Q = 1.5  (constant Q)
// RBJ band-pass, constant 0 dB peak gain (then divide all by a0):
b0 =  alpha;  b1 = 0;  b2 = -alpha;
a0 =  1 + alpha;  a1 = -2·cos(w0);  a2 = 1 - alpha;
float mx_bp = biquad(mx, state.mag_hp_x, b0,b1,b2,a1,a2);   // coeffs recomputed each tick
float my_bp = biquad(my, state.mag_hp_y, b0,b1,b2,a1,a2);
```

Why this filter:
- **Transmission zero at DC** (`b0+b1+b2 = 0`) → hard-iron / average-current offset
  is killed *exactly*, at any spin rate.
- **Peak at `f_rot`** with a roll-off above → rejects the 167 Hz sampling tone,
  which a *fixed* filter cannot (167 Hz is only ~2.5–4× the 40–66 Hz spin).
- **Tracks `omega_from_accel`**, so the pass-band follows the spin as it changes
  while staying independent of the heading the band-pass itself produces.

**Constant-Q, not fixed-Hz bandwidth.** The accelerometer's spin-rate estimate is
off by a *fraction* (measured +2…+12% on the bench; combat adds linear
acceleration + impacts, so budget ~2× ≈ 30%). A fixed ±N Hz band would slide off
the true signal at high spin. With constant `Q`, the −3 dB half-bandwidth is a
fixed fraction of the centre: `fc/(2Q) = fc/3 ≈ ±33%` at `Q = 1.5`. So the band is
≈ `0.67·f_rot … 1.33·f_rot`, comfortably wider than the bias even in messy combat,
and the true Earth sine always stays in-band (worst case only −3 dB at the edge).
Lower `Q` = wider/more robust; higher `Q` = narrower/cleaner.

**Combining the two axes (atan2).** `mx_bp` and `my_bp` are *not* two independent
references — they are the **quadrature (cos / −sin) components of one rotating
vector**: `mx_bp ≈ E·cos(φ−θ)`, `my_bp ≈ −E·sin(φ−θ)`. `atan2` returns that
vector's angle, i.e. the absolute heading, using **both** axes every sample:

```c
mag_angle = atan2(-my_bp, mx_bp);
```

They are 90° apart (X is at its zero where Y is at its peak and vice-versa), which
is exactly what `atan2` needs to resolve a full, unambiguous 0–360° heading
continuously — strictly better than reading one axis' zero-crossings (which give
heading only twice per axis per rev). The `-my` matches the LIS3MDL y-axis
inversion (DEBUGGING.md) so heading increases with `kf_theta` (CCW positive).

**This is OPEN-LOOP** — neither the heading nor the band centre uses the `θ`/`ω`
*estimate*: the angle is a pure `atan2` of the band-passed axes, and the band
centre comes from `omega_from_accel` (a direct accel measurement). So the heading
**cannot drift**. This independence is essential, not incidental: an earlier
revision centred the band on `kf_omega`, but because the band-pass output feeds
`kf_omega` back, the per-tick coefficient retuning from that fed-back rate
**parametrically false-locked the recovered heading at half the true spin rate**
(verified in sim: true 201.7 rad/s → recovered 108.6). Centring on the
loop-independent accel rate breaks that loop. Mis-centring (e.g. the accel's few-%
bias) merely attenuates the signal — it never biases the angle, because a *fixed*
band-pass is LTI and preserves the input frequency. The constant declination
offset `φ_earth` and the band-pass's constant group-delay phase are both absorbed
by `theta_offset` (the driver zero).

### Implementation, minimum speed, and the soft-iron wobble

One 2nd-order Direct Form II biquad per axis; state in
`SunshineState.mag_hp_x[2]` / `mag_hp_y[2]`. The coefficients are recomputed each
tick from `kf_omega` (a few transcendental ops — negligible at 1 kHz; the spin
rate, hence the coeffs, changes slowly).

The mag update is gated off below `SUNSHINE_MAG_MIN_OMEGA = 16π rad/s` (8 Hz spin
= **480 RPM**). The band's lower edge is ≈ `0.75·f_rot`; below 8 Hz that edge sinks
toward the slow average-current band where the 2nd-order skirt (~6 dB/oct, not a
brick wall) no longer rejects it well, and the tangential-acceleration inflation
of `omega_from_accel` becomes large. (Hard-iron DC itself never constrains the
minimum — the band-pass zeros it at any speed.)

The per-sample heading is noisy (1 kHz low-power mode), so the Kalman trusts it
moderately (`KF_R_MAG = 0.01`) and averages it down; because the measurement is
absolute, that denoising cannot add drift. One real imperfection: the two mag axes
are not equal-gain (measured amplitude ratio ≈ 1.44 → the `(x,y)` locus is an
**ellipse**, not a circle), which gives `atan2` a **±~10° 2/rev error**. It is
**zero-mean**, so it does *not* move the LED (no drift) — it just adds a few
degrees of wobble to the otherwise-stationary lit point. A soft-iron calibration
(ellipse fit → rescale/de-skew the axes before `atan2`) would sharpen it but isn't
required.

---

## Step 3: Kalman Filter

A 2-state linear Kalman filter estimates `[θ, ω]` at 1 kHz.

### State and model

State vector: `x = [θ (rad), ω (rad/s)]`

Motion model (constant angular velocity): angular velocity is assumed constant between steps, with θ integrating ω:

```
x[k+1] = F × x[k]

F = [[1, dt],
     [0,  1]]    where dt = 0.001 s
```

### Predict step (every tick)

```
x = F × x          →   θ += ω × dt
P = F × P × Fᵀ + Q →   P propagates with added process noise Q
```

Q is diagonal: `Q = diag(KF_Q_THETA, KF_Q_OMEGA)`. It models how much the true state drifts from the model prediction each tick.

After predict:
```
P[0,0] += P[1,0]×dt + P[0,1]×dt + P[1,1]×dt² + KF_Q_THETA
P[0,1] += P[1,1]×dt
P[1,0] += P[1,1]×dt
P[1,1] += KF_Q_OMEGA
```

### Update — Accelerometer (H = [0, 1], measures ω)

Innovation: `y = omega_from_accel - ω_estimated`

Kalman gain (simplified for H = [0,1]):
```
S = P[1,1] + KF_R_ACCEL
K = [P[0,1]/S, P[1,1]/S]
```

State and covariance update:
```
θ += K[0] × y
ω += K[1] × y
P -= K × H × P     (scalar × matrix)
```

This update is skipped when `accel_saturated = 1`.

### Update — Magnetometer (H = [1, 0], measures θ)

Innovation: `y = wrap_to_pi(mag_angle - θ_estimated)` (wrapped to [-π, π] to handle angle wraps)

Kalman gain (simplified for H = [1,0]):
```
S = P[0,0] + KF_R_MAG
K = [P[0,0]/S, P[1,0]/S]
```

State and covariance update:
```
θ += K[0] × y
ω += K[1] × y
P -= K × H × P
```

This update is skipped when `est_omega < SUNSHINE_MAG_MIN_OMEGA` (16π rad/s ≈ 480 RPM).

### The accel is the rate sensor; the mag is the absolute angle

The accelerometer is trusted for `ω` at all times (`KF_R_ACCEL`), so `kf_omega`
tracks `omega_from_accel`. The accel-derived ω is biased a few percent (effective
IMU radius ≠ the assumed 11 mm, plus tangential acceleration), but that bias no
longer matters for the heading: Step 2 is open-loop and centred on the accel rate
(not the estimate), so a biased rate only mis-centres the band-pass slightly
(attenuation, never an angle bias). An earlier revision down-weighted the accel
once the mag "locked" (a now-removed `KF_R_ACCEL_LOCKED`) to stop a heading
precession — but that precession was a property of the old closed-loop
demodulator, not of trusting the accel, so the down-weighting is gone.

### No derotation feedback

The filter is genuinely linear: the mag update is a normal absolute-angle
measurement, not a function of the estimate, and the band-pass centre is a direct
accel measurement. There is no derot bootstrap and no closed-loop drift mode — the
mag pins `θ` absolutely and the accel supplies the high-bandwidth rate.

At startup the filter has high uncertainty (`P = diag(100, …)`). The accel update
locks in `ω` within a few seconds; the mag update corrects `θ` once the robot
passes the mag-valid threshold (480 RPM) and the band-pass has settled (~1 s).

---

## Summary: Signal at Each Stage

```
At 500 RPM steady spin, 50 µT Earth field:

accel_x, accel_y     ≈ ±100 counts (centripetal at 45°)
centripetal_ms2      ≈ 70 m/s²
omega_from_accel     ≈ 52 rad/s (500 RPM ≈ 52.4 rad/s) ✓

mag_x, mag_y         ≈ DC offset (hard-iron + avg current) + Earth sine
                       oscillating at 8.3 Hz (500 RPM), ~±380 counts (~22 µT)

After high-pass (per axis):
mag_x_filt, mag_y_filt ≈ the zero-centred Earth sine (DC offset removed)

mag_angle            = atan2(-mag_y_filt, mag_x_filt) = absolute heading
                       (open-loop; offset φ_earth absorbed by theta_offset)

Kalman output:
est_omega            ≈ 52.4 rad/s (matches omega_from_accel at steady state)
est_theta            = robot absolute angle, unwrapped (grows monotonically)
```

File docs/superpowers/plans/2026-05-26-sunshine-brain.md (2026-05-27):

# sunshine_brain Implementation Plan

> **For agentic workers:** REQUIRED SUB-SKILL: Use superpowers:subagent-driven-development (recommended) or superpowers:executing-plans to implement this plan task-by-task. Steps use checkbox (`- [ ]`) syntax for tracking.

**Goal:** Build the ESP32-S3 brain firmware: sensor drivers, bidirectional DShot 600, FreeRTOS two-core task structure, and the 1 kHz nav+control loop that calls `sunshine_step()`.

**Architecture:** Core 1 owns the 1 kHz hard-real-time loop (sensors → `sunshine_step()` → DShot + LED → ring buffer). Core 0 owns the telemetry task (drains ring buffer → 50 Hz ESP-NOW TX; receives 500 Hz control packets from receiver and stores them behind a mutex). Five `platformio.ini` bringup environments gate features at compile time so each subsystem can be tested in isolation before the next is added.

**Tech Stack:** PlatformIO, ESP32-S3, Arduino framework (esp-idf ≥ 6.0), Adafruit ADXL375 library, Adafruit LIS3MDL library, DShotRMT_NEO, ESP-NOW v2.0, FreeRTOS, sunshine_core (compiled as a library).

**Prerequisite:** `sunshine_core` plan complete — `sunshine_core/` directory with all sources must exist before Task 7.

---

## File Structure

```
sunshine_brain/
├── platformio.ini
├── lib/
│   └── sunshine_core/             # symlink or copy of ../sunshine_core/
│       ├── library.json
│       ├── include/sunshine_core.h
│       └── src/{utils,kalman,derot_filter,control,brain}.c
├── include/
│   ├── bringup.h                  # BRINGUP_LEVEL feature gates
│   └── config.h                   # pin assignments, MAC addresses, constants
└── src/
    ├── main.cpp                   # setup(), loop(), error LED patterns
    ├── sensors/
    │   ├── adxl375.h + adxl375.cpp   # ADXL375 SPI driver wrapper
    │   └── lis3mdl.h + lis3mdl.cpp   # LIS3MDL SPI driver wrapper
    ├── dshot.h + dshot.cpp            # DShotRMT_NEO wrapper, eRPM telemetry
    ├── ring_buffer.h                  # Lock-free(ish) 40-entry ring buffer
    ├── telemetry.h + telemetry.cpp    # Core 0 task: ESP-NOW TX/RX
    └── nav_control.h + nav_control.cpp  # Core 1: 1 kHz loop
```

---

## Task 1: PlatformIO Setup + bringup.h + config.h

**Files:**
- Create: `sunshine_brain/platformio.ini`
- Create: `sunshine_brain/include/bringup.h`
- Create: `sunshine_brain/include/config.h`

- [ ] **Step 1: Create platformio.ini**

```ini
[env_base]
platform    = https://github.com/pioarduino/platform-espressif32/releases/download/stable/platform-espressif32.zip
board       = esp32-s3-devkitc-1
framework   = arduino
monitor_speed  = 921600
upload_speed   = 921600
build_flags    =
    -DARDUINO_USB_CDC_ON_BOOT=1
    -DCORE_DEBUG_LEVEL=0
lib_deps =
    adafruit/Adafruit ADXL375 @ ^1.0.0
    adafruit/Adafruit LIS3MDL @ ^1.2.0
    qqqlab/DShotRMT_NEO @ ^1.0.0

[env:bringup_1_sensors]
extends    = env_base
build_flags = ${env_base.build_flags} -DBRINGUP_LEVEL=1

[env:bringup_2_dshot]
extends    = env_base
build_flags = ${env_base.build_flags} -DBRINGUP_LEVEL=2

[env:bringup_3_telemetry]
extends    = env_base
build_flags = ${env_base.build_flags} -DBRINGUP_LEVEL=3

[env:bringup_4_navigation]
extends    = env_base
build_flags = ${env_base.build_flags} -DBRINGUP_LEVEL=4

[env:production]
extends    = env_base
build_flags = ${env_base.build_flags} -DBRINGUP_LEVEL=0
```

> **Platform note:** The pioarduino `stable` URL currently fails with `MissingPackageManifestError` when `framework-arduinoespressif32-libs` tries to install from the official arduino-esp32 release tarball. If the brain project fails to build, pin the platform to a known-good release or wait for pioarduino to fix the `stable` pointer. The receiver was temporarily built against `espressif32@6.0.0` (IDF 4.4) as a workaround; once pioarduino is fixed both projects should use the URL above.

- [ ] **Step 2: Create include/bringup.h**

```cpp
#pragma once

// BRINGUP_LEVEL controls which features are compiled in.
// 0 = production (all features), 1-4 = incremental bringup.
//
// Level 1: sensors CSV on USB serial only (no ESP-NOW, no DShot)
// Level 2: + DShot interactive test (no telemetry)
// Level 3: + ESP-NOW telemetry, no navigation filter updates (zeros dshot)
// Level 4: + full navigation (kalman, derot filter), still zeros dshot for safety
// Level 0: production — all features, full control output

#ifndef BRINGUP_LEVEL
#define BRINGUP_LEVEL 0
#endif

// Feature gates derived from level
#if BRINGUP_LEVEL == 0 || BRINGUP_LEVEL >= 2
#  define FEATURE_DSHOT     1
#else
#  define FEATURE_DSHOT     0
#endif

#if BRINGUP_LEVEL == 0 || BRINGUP_LEVEL >= 3
#  define FEATURE_TELEMETRY 1
#else
#  define FEATURE_TELEMETRY 0
#endif

#if BRINGUP_LEVEL == 0 || BRINGUP_LEVEL >= 4
#  define FEATURE_NAVIGATION 1
#else
#  define FEATURE_NAVIGATION 0
#endif

// At levels 3-4 we always zero the dshot outputs for safety (no actual drive)
#if BRINGUP_LEVEL >= 3 && BRINGUP_LEVEL <= 4
#  define FORCE_DSHOT_ZERO 1
#else
#  define FORCE_DSHOT_ZERO 0
#endif
```

- [ ] **Step 3: Create include/config.h**

```cpp
#pragma once
#include <stdint.h>

// ── SPI pins ──────────────────────────────────────────────────────────────────
// FSPI → ADXL375
#define PIN_ADXL_CS    10
#define PIN_ADXL_MOSI  11
#define PIN_ADXL_SCK   12
#define PIN_ADXL_MISO  13
// INT pins (not used in polled mode, reserved)
#define PIN_ADXL_INT1   8
#define PIN_ADXL_INT2   9

// HSPI → LIS3MDL
#define PIN_MAG_CS      18
#define PIN_MAG_MOSI    15
#define PIN_MAG_SCK     16
#define PIN_MAG_MISO    17
#define PIN_MAG_DRDY    14
#define PIN_MAG_INT     21

// ── DShot ─────────────────────────────────────────────────────────────────────
#define PIN_DSHOT_LEFT   4   // S1
#define PIN_DSHOT_RIGHT  5   // S2

// ── Battery ADC ───────────────────────────────────────────────────────────────
#define PIN_BATT_ADC    39
// V = adc_raw * (3.3/4095) * (R_high+R_low)/R_low = adc_raw * (3.3/4095) * 3.0
static constexpr float BATT_ADC_SCALE = (3.3f / 4095.0f) * 3.0f;

// ── LED ───────────────────────────────────────────────────────────────────────
// LED is active-high (gate of low-side switch). Reuse whichever GPIO is
// available on your board. Fill in the actual pin.
#define PIN_LED          2   // CHANGE if your board uses a different pin

// ── Timing ────────────────────────────────────────────────────────────────────
static constexpr uint32_t LOOP_INTERVAL_US   = 1000;  // 1 kHz
static constexpr uint32_t TELEMETRY_FRAMES   = 20;    // inputs per 50 Hz frame
static constexpr uint32_t CTRL_WATCHDOG_MS   = 500;   // no ctrl → DISABLED

// ── ESP-NOW ───────────────────────────────────────────────────────────────────
static constexpr uint8_t ESPNOW_CHANNEL      = 1;
// Receiver MAC — fill in after running receiver and noting its WiFi STA MAC
static const uint8_t RECEIVER_MAC[6]         = {0xXX, 0xXX, 0xXX, 0xXX, 0xXX, 0xXX};
```

- [ ] **Step 4: Create sunshine_core library.json**

PlatformIO needs a `library.json` to pick up the local source directory:

```bash
mkdir -p sunshine_brain/lib/sunshine_core
```

Create `sunshine_brain/lib/sunshine_core/library.json`:
```json
{
  "name": "sunshine_core",
  "version": "1.0.0",
  "build": {
    "srcDir": ".",
    "includeDir": "."
  }
}
```

Then create symlinks so PlatformIO sees the sources:
```bash
ln -s ../../../../sunshine_core/include/sunshine_core.h \
      sunshine_brain/lib/sunshine_core/sunshine_core.h
ln -s ../../../../sunshine_core/src/utils.c       sunshine_brain/lib/sunshine_core/utils.c
ln -s ../../../../sunshine_core/src/kalman.c      sunshine_brain/lib/sunshine_core/kalman.c
ln -s ../../../../sunshine_core/src/derot_filter.c sunshine_brain/lib/sunshine_core/derot_filter.c
ln -s ../../../../sunshine_core/src/control.c     sunshine_brain/lib/sunshine_core/control.c
ln -s ../../../../sunshine_core/src/brain.c       sunshine_brain/lib/sunshine_core/brain.c
```

- [ ] **Step 5: Add stub src/main.cpp and compile**

```cpp
// src/main.cpp (stub — replaced in later tasks)
#include "bringup.h"
#include "config.h"
#include <Arduino.h>
void setup() { Serial.begin(921600); }
void loop()  { delay(1000); }
```

```bash
cd sunshine_brain && pio run --environment bringup_1_sensors 2>&1 | tail -10
```
Expected: firmware.bin built, no errors.

- [ ] **Step 6: Commit**

```bash
git add sunshine_brain/
git commit -m "feat(brain): PlatformIO project scaffold, bringup gates, sunshine_core lib"
```

---
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

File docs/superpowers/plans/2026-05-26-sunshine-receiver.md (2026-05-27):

# sunshine_receiver Implementation Plan

> **For agentic workers:** REQUIRED SUB-SKILL: Use superpowers:subagent-driven-development (recommended) or superpowers:executing-plans to implement this plan task-by-task. Steps use checkbox (`- [ ]`) syntax for tracking.

**Goal:** Build the ESP32-S3 receiver firmware that bridges ESP-NOW (from brain) to USB serial (to host app) and sends 500 Hz control packets back to the brain.

**Architecture:** Two FreeRTOS tasks. Core 0 handles the ESP-NOW RX callback (stores latest telemetry frame in a double buffer). Core 1 runs a continuous loop: reads USB from host, forwards telemetry frames to host at 50 Hz, and drives a 500 Hz `esp_timer` that sends control packets to the brain. A 3-second host-silence watchdog forces `mode=DISABLED` on the 500 Hz output.

**Tech Stack:** PlatformIO, ESP32-S3, Arduino framework (esp-idf 6.0+), ESP-NOW v2.0, FreeRTOS, `esp_timer`.

---

## File Structure

```
sunshine_receiver/
├── platformio.ini
├── include/
│   ├── config.h          # MAC addresses, timing constants
│   └── protocol.h        # USB frame format, type codes, encode/decode
├── src/
│   ├── main.cpp          # setup() + task creation + ESP-NOW init
│   ├── espnow_rx.cpp     # ESP-NOW RX callback + double buffer
│   └── usb_bridge.cpp    # 500 Hz timer, USB TX/RX, watchdog, heartbeat
└── lib/                  # (empty — all deps via platformio.ini)
```

---

## Task 1: PlatformIO Setup + config.h

**Files:**
- Create: `sunshine_receiver/platformio.ini`
- Create: `sunshine_receiver/include/config.h`

- [ ] **Step 1: Create platformio.ini**

```ini
[env:receiver]
platform = espressif32 @ 6.0.0
board = esp32-s3-devkitc-1
framework = arduino
monitor_speed = 921600
upload_speed = 921600
build_flags =
    -DCORE_DEBUG_LEVEL=0
    -DARDUINO_USB_CDC_ON_BOOT=1
```

`ARDUINO_USB_CDC_ON_BOOT=1` routes `Serial` to the native USB CDC port so we get maximum bandwidth without UART overhead.

> **Platform note:** The receiver uses `espressif32@6.0.0` (IDF 4.4) rather than the pioarduino URL, because the pioarduino `stable` URL currently fails with `MissingPackageManifestError` (the `framework-arduinoespressif32-libs` package can't be installed from the official arduino-esp32 release tarball). IDF 4.4's `esp_now_recv_cb_t` does not expose `esp_now_recv_info_t`, so receiver-side RSSI is not available from the callback — `espnow_rx_update_rssi(int8_t)` is a hook for a promiscuous sniffer task. When the pioarduino platform is fixed (both brain and receiver), switch the receiver to the same pioarduino URL to get IDF 5.x and remove the sniffer workaround.

- [ ] **Step 2: Create include/config.h**

```cpp
#pragma once
#include <stdint.h>

// ── Brain MAC address ────────────────────────────────────────────────────────
// Fill in the actual MAC from the brain's WiFi STA interface.
// Run `WiFi.macAddress()` on brain to read it.
static const uint8_t BRAIN_MAC[6] = {0xXX, 0xXX, 0xXX, 0xXX, 0xXX, 0xXX};
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

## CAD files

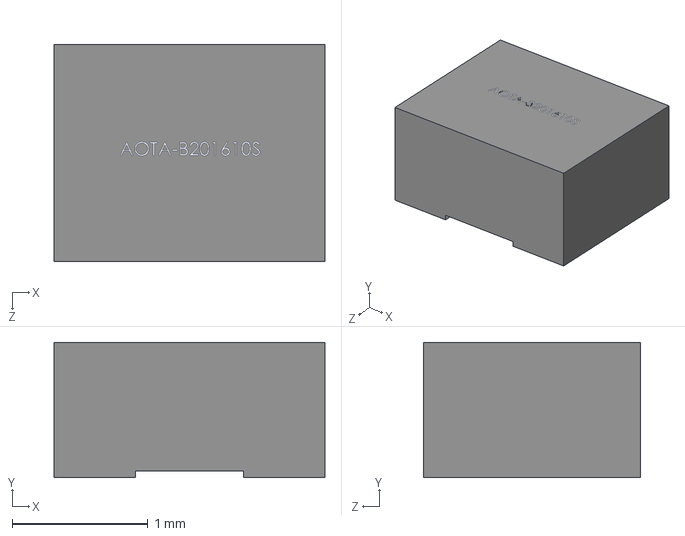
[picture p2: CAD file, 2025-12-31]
sunshine_pcb/custom/footprint/AOTA-B201610SR47MT--3DModel-STEP-368357.STEP
2.00 x 1.00 x 1.60 mm

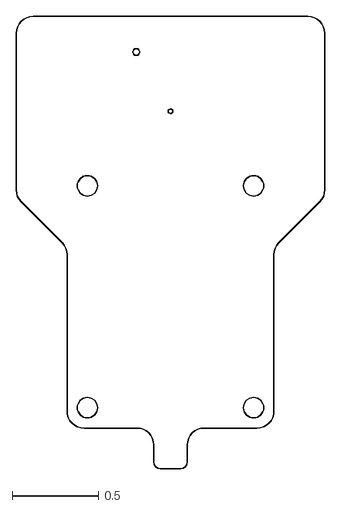
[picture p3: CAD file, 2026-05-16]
sunshine_pcb/sunshine_outline.dxf
1.79 x 2.63

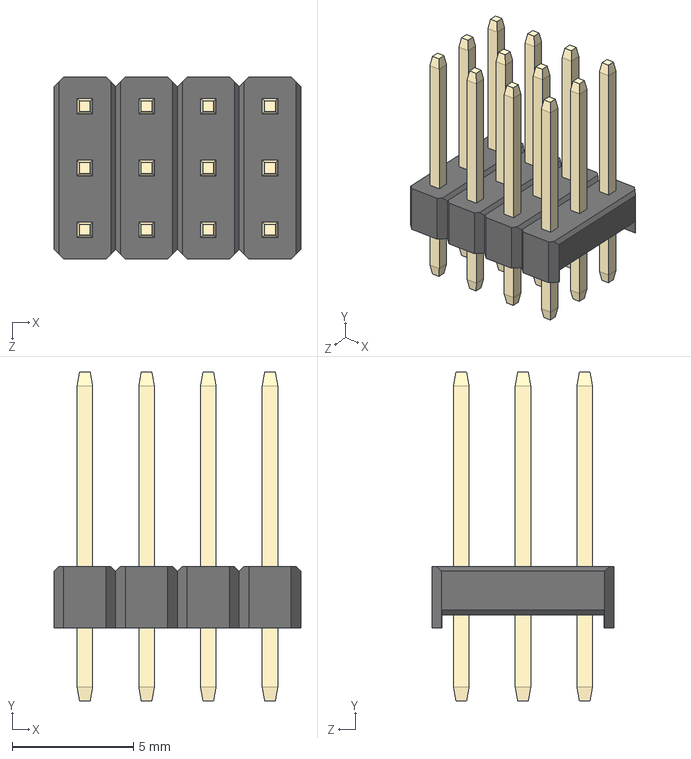
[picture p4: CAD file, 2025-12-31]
sunshine_pcb/custom/footprint/3x4 Male Pin Header.STEP
10.2 x 13.5 x 7.50 mm

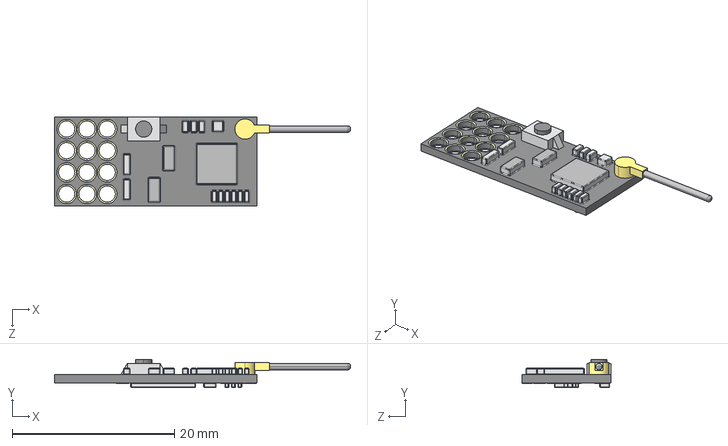
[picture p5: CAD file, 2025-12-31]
sunshine_pcb/custom/footprint/FS2a-mini.STEP
36.5 x 3.50 x 11.0 mm

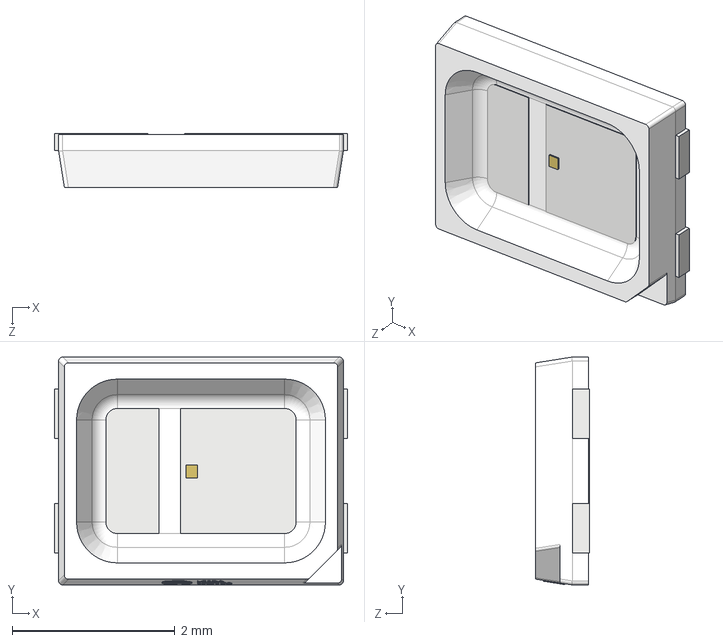
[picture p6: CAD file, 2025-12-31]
sunshine_pcb/custom/footprint/LED-SMD_L3.5-W2.8_RED.step
3.60 x 2.80 x 0.66 mm

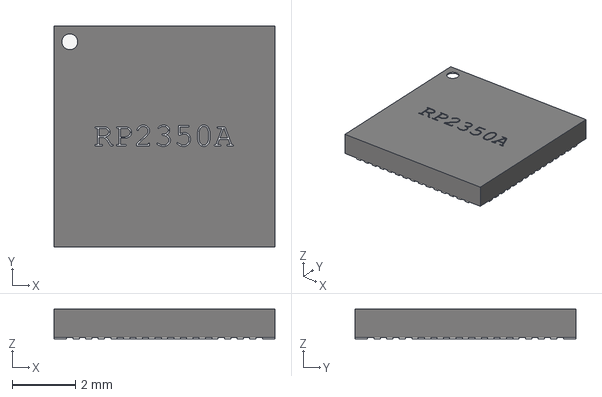
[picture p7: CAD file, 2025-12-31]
sunshine_pcb/custom/footprint/RP2350_QFN60.step
7.00 x 7.00 x 0.95 mm

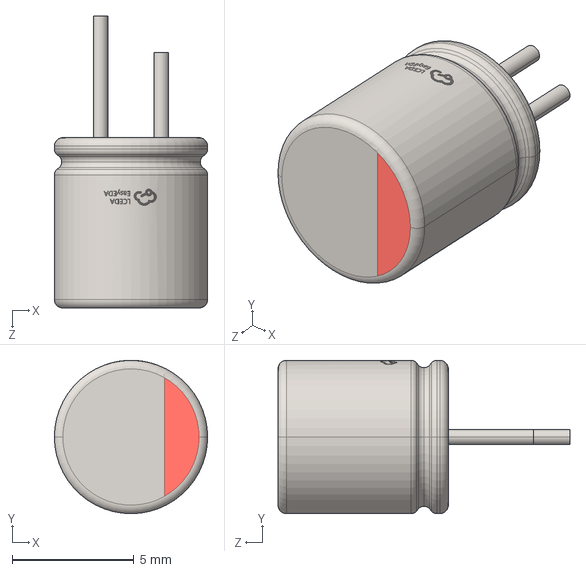
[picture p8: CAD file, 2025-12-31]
sunshine_pcb/custom/footprint/CAP-TH_BD6.3-P2.50-D0.6-FD-1.step
6.30 x 6.30 x 12.0 mm

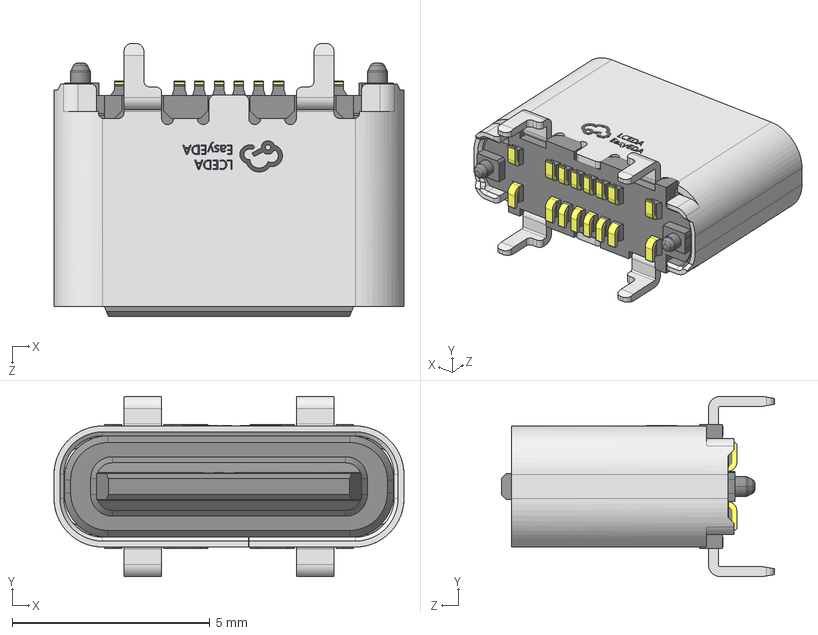
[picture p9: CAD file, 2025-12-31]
sunshine_pcb/custom/footprint/USB-C-SMD_GT-USB-7055E.step
8.84 x 4.55 x 6.90 mm

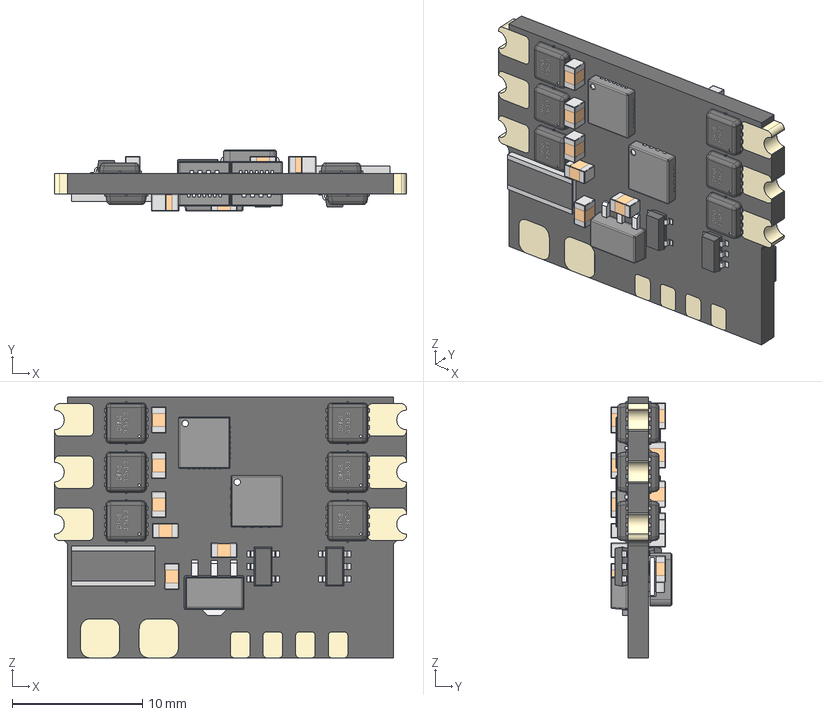
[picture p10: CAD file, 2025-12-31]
sunshine_pcb/custom/footprint/Repeat AM32 Dual Brushless Drive ESC v9.step
27.0 x 4.70 x 20.0 mm
PCB
PDFN3333 (DFN8 3.3x3.3) x 12
SOT23-5 x 3
WE_Inductor_4020
TPS51385
Yageo-RC1218 x 2
ceramic_cap_0805 v1 x 14

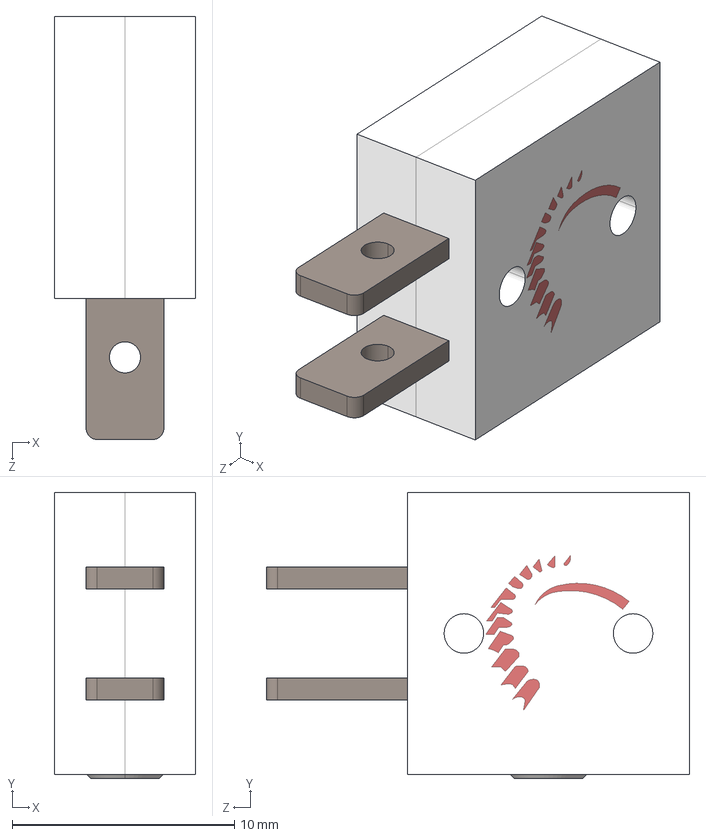
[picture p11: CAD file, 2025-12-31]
sunshine_pcb/custom/footprint/Fingertech Mini Power Switch.STEP
6.35 x 12.9 x 19.1 mm
PART A x 2
socket head cap screw_ai_HX-SHCS 0.086-56x0.375x0.375-S
TERMINAL x 2

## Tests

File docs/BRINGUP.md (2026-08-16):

# Sunshine Bringup Guide

Step-by-step bringup instructions for all five levels. Work through them in order. Each level builds on the previous.

**Before you start:** Read `ARCHITECTURE.md` for the big picture.

---

## Platform Notes (Read First)

### Brain — pioarduino platform issue

The brain's `platformio.ini` uses the pioarduino `stable` release URL. As of 2026-05-26 it fails during `pio run` with:

```
PackageInstallError: MissingPackageManifestError on framework-arduinoespressif32-libs
```

**Workaround:** Pin the platform to a known-good pioarduino release. Edit `sunshine_brain/platformio.ini`:

```ini
# Replace the platform line in [env_base] with a pinned release, e.g.:
platform = https://github.com/pioarduino/platform-espressif32/releases/download/51.03.07/platform-espressif32.zip
```

Check [github.com/pioarduino/platform-espressif32/releases](https://github.com/pioarduino/platform-espressif32/releases) for the latest working release. Once pioarduino fixes the `stable` pointer, revert to the URL in the file.

### Receiver — IDF 4.4 (espressif32@6.0.0)

The receiver is built against `espressif32@6.0.0` (IDF 4.4). This affects two things:

1. **Receiver-side RSSI**: The IDF 4.4 `esp_now_recv_cb_t` signature does not expose RSSI. `espnow_rx_get_rssi()` returns -127. The `RX_RSSI` USB packet will always be -127 until the receiver is rebuilt on IDF 5.x. Brain-side RSSI (`inputs.rssi`) is unaffected — it reads fine.
2. **ESP-NOW callback signature**: The existing `espnow_rx.cpp` uses the IDF 4.x signature (`const uint8_t *mac_addr, const uint8_t *data, int len`). If you later migrate to IDF 5.x, change the callback to `const esp_now_recv_info_t *info, const uint8_t *data, int len` and read RSSI from `info->rx_ctrl->rssi`.

### DShot library

`sunshine_brain/platformio.ini` uses `derdoktor667/DShotRMT @ ^0.9.5` (not `qqqlab/DShotRMT_NEO` as originally planned — that package was unavailable). If DShot arming fails, check the library's examples for the correct arming procedure with AM32 in 3D mode.

---

## Porting to a New Robot

This codebase brings up **any two-wheel meltybrain that uses the same brain PCB** — different frame, wheels, motors, ESC ratings, mass. The port is: change the per-build constants below, then run Levels 1–5 in order. Everything else (schema, telemetry, replay, app) is robot-independent.

### Where the per-build constants live

| File | Constants | Consumed by |
|---|---|---|
| `sunshine_core/include/sunshine_core.h` | **The one file with every per-robot number.** Drivetrain block: `WHEEL_RADIUS_M`, `WHEEL_CENTER_M`, `MOTOR_KV_RPM_PER_V` (nameplate, do **not** derate — see comment there), `MOTOR_POLE_PAIRS`, `WHEEL_SLIP_ALLOW_MS`. Geometry: `IMU_RADIUS_M` (accel distance from spin axis). Measured: `DRIFT_PHASE_LEAD_S` (Level 5 Step 4 below). Plant/environment block (used by the host **simulation** only, but kept here so nothing per-robot lives anywhere else): `ROBOT_MASS_KG`, `ROBOT_MOI_KGM2`, `WHEEL_INERTIA_KGM2`, `MOTOR_R_PHASE_OHM`, `BATT_NOMINAL_V`, `BATT_R_INTERNAL_OHM`, `EARTH_FIELD_UT`, `EARTH_ANGLE_RAD`, `HARD_IRON_X/Y_UT`, `MAG_HF_TONE_*`, `SIM_*` model fudge factors. | Brain firmware, host app, replay tool, and unit tests all **link this one header**. The app's `build.rs` additionally **parses it and generates the Rust constants** for `simulation.rs` at build time — there is no hand-synced copy anywhere; change the header, rebuild, done. |
| `sunshine_brain/include/config.h` | Pins, `BATT_ADC_SCALE`, SPI wiring — **unchanged on the same PCB**. Per-build: `MOTOR_LEFT_INVERT` / `MOTOR_RIGHT_INVERT` (Level 2 Step 5), `ESPNOW_CHANNEL`. | Brain firmware only. |
| `sunshine_receiver/include/config.h` | `BRAIN_MAC` (Level 3 Step 1). | Receiver firmware only. |

Cosmetic only: the KV label in `sunshine_app/src/components/DriverStation.tsx`. The sensor scale factors (`ADXL_SCALE_MS2`, `MAG_SCALE_UT`, battery encoding) also appear in `pipeline.rs`/`StatusBar.tsx`, but they are properties of the PCB's sensors, not of the robot build — leave them alone.

### How to obtain the plant/environment numbers

- `ROBOT_MASS_KG` — kitchen scale.
- `ROBOT_MOI_KGM2` — CAD (preferred), or bifilar-pendulum measurement.
- `WHEEL_INERTIA_KGM2` — CAD, or `½·m_wheel·r²` as a first cut (includes motor rotor).
- `MOTOR_R_PHASE_OHM` — motor datasheet, or multimeter across two phases ÷ 2.
- `HARD_IRON_X_UT` / `HARD_IRON_Y_UT` — from any Level 3+ log: mean of raw `inputs.mag_x` / `inputs.mag_y` while spinning, × 0.058 µT/count. (The heading filter kills hard-iron by construction; the sim needs it only to *generate* realistic mag data.)
- `EARTH_FIELD_UT` — horizontal field strength for your location (NOAA calculator). Horizontal component **only**, not total.

### What "fully brought up" means

After Level 5, all of these work for the new robot with no further code changes: live driving (TANK + MELTY with translation), telemetry + logging, **replay** (`tools/replay/` links the same core, so `replay`, `analyze.py`, `translation_lag.py`, `erpm_bandwidth.py`, `wheel_slip.py`, `spinup_lag.py` are all robot-agnostic or read the new constants), and **simulation** (its constants are generated from the same header at build time). The unit tests (`build/ctest`) assert physical invariants against whatever constants are compiled, with one exception: the `DRIFT_PHASE_LEAD_S` band in `test_control.c` encodes this robot's measured delay — after Level 5 Step 4, retarget that band to the new measurement.

---

## Level 1 — Low-level Sensors

**Goal:** All three sensors init and read correctly.  
**Setup:** Brain board powered via USB, **no ESCs connected**.  
**Firmware environment:** `bringup_1_sensors`

### Step 1: Build and flash

```bash
cd sunshine_brain
pio run --environment bringup_1_sensors
pio run --target upload --environment bringup_1_sensors
```

If the build fails with `MissingPackageManifestError`, apply the pioarduino workaround above.

### Step 2: Open serial monitor

```bash
pio device monitor --baud 921600
```

Expected output: a CSV header line followed by comma-separated values at ~100 Hz:

```
accel_x,accel_y,accel_z,mag_x,mag_y,mag_z,batt_v
-1,0,20,-342,512,-198,8.35
...
```

### Step 3: Verify each sensor

| Sensor | Field(s) | Expected at rest | Action to verify |
|---|---|---|---|
| ADXL375 | `accel_z` | ≈ +20 counts (1g / 0.049g per count) | Shake board → all axes spike |
| LIS3MDL | `mag_x,y,z` | magnitude ≈ 860 counts (50 µT / 0.058 µT/count) | Rotate board → `mag_x` and `mag_y` trace a circle |
| Battery ADC | `batt_v` | Matches multimeter reading ±0.1V | Verify with multimeter |

### Pass criteria

- No LED error blink pattern
- `accel_z` within ±5 counts of 20 at rest
- mag magnitude `sqrt(x²+y²+z²)` between 700 and 1000 counts
- `batt_v` within 0.1V of multimeter

**Troubleshooting:**

- 1 blink → ADXL375 init failed. Check FSPI wiring: SCK=IO12, MOSI=IO11, MISO=IO13, CS=IO10.
- 2 blinks → LIS3MDL init failed. Check HSPI wiring: SCK=IO16, MOSI=IO15, MISO=IO17, CS=IO18.
- `accel_z ≈ 0` → ADXL375 returning zero. Check SPI mode (should be SPI_MODE3) and full-resolution flag.
- `batt_v ≈ 0` → ADC not reading. `PIN_BATT_ADC = 7` (GPIO7, ADC1_CH7). Check `analogReadResolution(12)` is called in setup.
- `batt_v` noisy / jumpy while spinning → expected: the ESCs inject a strong ~50 Hz (2×-spin) tone. `batt_read_v()` low-passes it (single-pole IIR at `BATT_LP_HZ`, default 6 Hz in `config.h`). Raise `BATT_LP_HZ` for snappier sag response, lower for a smoother trace. As of schema v5 `batt_offset` is **int16 at 1 mV/LSB** (was int8 at 20.5 mV), so telemetry no longer discretises the battery — the 12-bit ADC (~2.4 mV) and the LP are the only quantisers left. Plot it as `var.batt_voltage`.

---

## Level 2 — DShot & ESC

**Goal:** Bidirectional DShot 600 working; eRPM telemetry readable.  
**Setup:** ESCs connected to IO4 (left) and IO5 (right). **Props removed.** AM32 pre-flashed in 3D mode with correct motor direction settings.  
**Firmware environment:** `bringup_2_dshot`

### Step 1: Pre-configure AM32 ESCs

Before connecting, use the AM32 configurator to set:
- Mode: 3D
- Motor direction: verify left and right motors spin in the correct directions when commanded forward

### Step 2: Build and flash

```bash
pio run --target upload --environment bringup_2_dshot
pio device monitor --baud 921600
```

Expected: `BRINGUP 2: DShot test. l <val>, r <val>, s, t`

### Step 3: Interactive test

The serial interface accepts single-line commands:

| Command | Action |
|---|---|
| `l 1200` | Left ESC: DShot value 1200 (forward) |
| `r 1200` | Right ESC: DShot value 1200 (forward) |
| `l 900` | Left ESC: DShot value 900 (reverse in 3D mode) |
| `s` | Stop both (sends neutral 1048) |
| `t` | Print eRPM for both ESCs |

AM32 3D mode DShot mapping:
- 48–1047: reverse (1047 = full reverse)
- 1048: neutral / brake
- 1049–2047: forward (2047 = full forward)

### Step 4: Verify eRPM

1. Send `l 1300`, wait 1 second, send `t`
2. Expected: `eRPM L=<value> R=0` where value > 0
3. Repeat several times — success rate should be > 90% (occasional 0 reads are acceptable)
4. Calculate expected eRPM: `KV × V_battery × pole_pairs`. For 1100 KV motor at 8V with 14 pole pairs: 1100 × 8 × 7 ≈ 61,600 eRPM at full throttle.

### Step 5: Set motor directions for CCW spin

**Goal:** In MELTY mode both motors spin "forward" (DShot > 1048) and the robot body rotates **counter-clockwise viewed from above**. This is the single correct spin direction.

The wheels are tangentially mounted, so both motors spinning "forward" produces body rotation. Which direction depends on physical motor mounting. Determine and fix it now.

#### 5a — Identify the correct direction per motor

With props off, secure the robot so it can't move (hand or clamp). Send equal forward commands to both motors and observe which way the body wants to rotate:

```
s          (neutral both)
l 1300
r 1300
```

- If the body torques **CCW** (viewed from above): correct, no inversion needed.
- If the body torques **CW**: both motors are backwards. You can either:
  - Swap motor leads on both ESCs (or swap any two of the three motor phases), **or**
  - Set `MOTOR_LEFT_INVERT = true` and `MOTOR_RIGHT_INVERT = true` in `sunshine_brain/include/config.h`.

If one motor spins the wrong way relative to the other, invert only that motor's flag.

#### 5b — Verify TANK mode translation

While still in bringup level 2 (or reflash level 3 and use the host app), command both motors for "TANK forward" — left forward + right reverse:

```
l 1300
r 800
```

The robot should push forward in the LED-defined direction. If it goes backward, your Y-axis is inverted — set `MOTOR_LEFT_INVERT` / `MOTOR_RIGHT_INVERT` accordingly so that the motion matches the control intent.

#### 5c — Software inversion vs AM32 configuration

Prefer AM32 motor direction (via the AM32 configurator) over the software flags — AM32 changes are persistent and work across all bringup levels without reflashing. Use the `MOTOR_LEFT_INVERT` / `MOTOR_RIGHT_INVERT` flags in `config.h` only when rewiring or AM32 reconfiguration isn't convenient.

### Pass criteria

- ESCs arm without beeping an error sequence
- Both directions spin when commanded
- eRPM telemetry success rate > 90% (`t` command rarely returns 0 while motor is spinning)
- Values are plausible given battery voltage
- Both motors commanded "forward" torques the body CCW (viewed from above)

---

## Level 3 — Telemetry Link

**Goal:** Full brain→receiver→host pipeline live in host app.  
**Setup:** Brain + receiver both powered. Host machine running the app. **Props off.**  
**Firmware environment:** `bringup_3_telemetry`

### Step 1: Set the brain MAC address in the receiver

The receiver needs the brain's WiFi STA MAC address hardcoded. To find it:

1. Flash any bringup level to the brain (level 1 is fine)
2. In brain's `main.cpp` setup, temporarily add:
   ```cpp
   WiFi.mode(WIFI_STA);
   Serial.println(WiFi.macAddress());
   ```
3. Read the MAC from serial monitor, e.g. `A4:CF:12:34:56:78`
4. Edit `sunshine_receiver/include/config.h`:
   ```cpp
   static const uint8_t BRAIN_MAC[6] = {0xA4, 0xCF, 0x12, 0x34, 0x56, 0x78};
   ```
5. Similarly, set the receiver MAC in `sunshine_brain/include/config.h` (read the receiver's MAC the same way)
6. Remove the temporary WiFi lines from brain's `main.cpp`

### Step 2: Flash receiver

```bash
cd sunshine_receiver
pio run --target upload --environment receiver
```

### Step 3: Flash brain

```bash
cd sunshine_brain
pio run --target upload --environment bringup_3_telemetry
```

Note: motor outputs are zeroed in this environment even if controls are sent.

### Step 4: Launch host app and connect

```bash
cd sunshine_app
pnpm tauri dev
```

In the app:
1. Go to the **Live** tab in ConnectionPanel
2. Select the receiver's serial port from the dropdown
3. Click **Connect**
4. Both status indicators (receiver + brain) should turn green within ~5 seconds

The receiver's onboard RGB LED tracks this independently of the app: **red** (no brain) → **amber** (brain up, host silent) → **green** with cyan flicker (full pipeline live). See the *Receiver Status LED Reference* below.

### Step 5: Verify the full pipeline

Open the graph panel and plot the following channels. Expected behavior at rest on a table:

| Channel | Expected |
|---|---|
| `inputs.accel_z` | Steady ≈ +20 counts. Shake board → spikes. |
| `inputs.mag_x` + `inputs.mag_y` | Non-zero, sinusoidal if you rotate the board |
| `inputs.rssi` | Plausible negative dBm (e.g. -55 to -80). Note: `RX_RSSI` packet reads -127 on IDF 4.4 — this is expected. |
| `inputs.ctrl_y` | Zero at rest. Press W key → ramps up smoothly (LP filter visible), releases → decays to zero. |

Check frame integrity: in the status bar, `frame_id` should increment without large gaps. Occasional missed frames are acceptable; continuous gaps indicate an ESP-NOW range or channel issue.

### Step 6: 2-minute stability test

Let the system run for 2 minutes without touching anything. Pass if:
- No `BRAIN_DISCONNECTED` status events appear
- `frame_id` gaps are rare (< 5% of frames)
- Log file created on connect, frame count incrementing in log status bar

### Pass criteria

- Both status indicators green
- Sensor data visible and plausible
- Control inputs visible when keys pressed
- Stable for 2 minutes

**Troubleshooting:**

- Brain shows as disconnected: check MAC addresses in both config files. Check ESP-NOW channel (both must be channel 1). Check receiver has power.
- `inputs.rssi` is -127: expected on IDF 4.4 (see platform notes at top of this file).
- Frame gaps > 20%: try moving receiver closer to brain. Check for 2.4 GHz interference (channel 1 overlaps WiFi channel 1).
- Host app doesn't see serial port: receiver may need `ARDUINO_USB_CDC_ON_BOOT=1` in its build flags (it should already be set).

---

## Level 4 — Navigation Tuning

**Goal:** Kalman filter tuned, LED appears stationary when spinning, TANK mode working.  
**Setup:** Full robot assembled, **props off** initially.  
**Firmware environment:** `bringup_4_navigation`

In this environment **TANK mode drives the motors** so you can spin the robot to tune the filters. DISABLED and MELTY keep the motors zeroed (MELTY isn't tuned until Level 5). The Kalman and magnetometer-heading filters run in all modes. **Props off.**

### Step 1: Flash and connect

```bash
cd sunshine_brain && pio run --target upload --environment bringup_4_navigation
```

Connect host app (same as Level 3). Plot `vars.est_omega` and `vars.omega_from_accel`.

### Step 2: Verify omega sensing

Spin the robot slowly by hand (without motors). In the graph:
- `omega_from_accel` should rise as you spin faster
- During spin-up, `omega_from_accel` reads high (tangential acceleration adds to centripetal magnitude — this is expected and normal, documented in `FILTER_MATH.md`)

### Step 3: Verify magnetometer heading

Spin the robot above the mag threshold (~480 RPM) by hand or with light motor power (with props off it's safe). Plot `vars.mag_x_filt` and `vars.mag_y_filt` — the band-passed Earth-field axes. They *oscillate* at the spin frequency (they're the rotating Earth sine), but their magnitude `sqrt(x²+y²)` should settle to a steady ~18–22 µT within ~1 s. If the magnitude is near zero, the spin is below threshold or `est_omega` is far off (so the spin frequency is outside the ±33% tracking band — fix Step 2 first). Also plot `vars.mag_angle` (the absolute heading) — it should rotate smoothly with the body.

**Do not carry a marginal magnetometer forward into Level 5.** The MELTY wheel-speed cap
takes its rate reference from the mag-driven `kf_omega`, so a mag that never locks holds
MELTY at the unlocked ceiling and the robot will not spin up at all (see Level 5, Step 2).
A mag that is *intermittent* is worse to diagnose than one that is dead: the spin will
stall and release at random. Fix it here.

### Step 4: Tune Kalman parameters

See `TUNING.md` for the full tuning procedure. Constants are in `sunshine_core/include/sunshine_core.h`. Change them and rebuild — no re-flash needed if you use `-D` build flags in `platformio.ini` for rapid iteration.

Summary of what each parameter controls:

| Parameter | Effect |
|---|---|
| `KF_Q_OMEGA` | Higher → faster omega tracking, more noise |
| `KF_R_ACCEL` | Accel ω weight (always); higher → less influence from accelerometer |
| `KF_Q_THETA` | Higher → faster angle tracking, more drift |
| `KF_R_MAG` | Higher → less influence from magnetometer |
| `MAG_BP_FC_LP_HZ` | Band-pass centre LP (default 1.5 Hz). Lower = steadier `mag_angle` (less translation-induced wobble); higher = tracks spin-up faster. See TUNING.md. |
| `MAG_SPIN_RATE_LP_HZ` | LP on the signed mag rotation rate (default 3.2 Hz) — used ONLY for the spin-direction sign since the 2026-08-15 revert (see TUNING.md "Angular-rate source"). Higher = faster sign response after a flip; lower = more noise-robust sign. |

**Check for `mag_angle` wobble during translation/impacts.** Plot `var.omega_from_accel`
and `real.mag_angle` while driving in TANK and bumping the robot. If `mag_angle` gets
jittery when the accel rate spikes, lower `MAG_BP_FC_LP_HZ`. (The LED itself should
stay solid — it's mag-anchored; this only affects the band-passed heading cleanliness.)

### Step 5: LED check

While spinning above the mag threshold (~480 RPM), the LED should appear as a stationary dot (a few degrees of wobble from the soft-iron ellipse is fine — see FILTER_MATH.md). If it *sweeps/precesses* around, the heading is drifting — the open-loop mag (band-pass centred on `omega_from_accel`) should prevent that, so trust the mag more (`KF_R_MAG` down). Confirm `omega_from_accel` is sane: if it is wildly wrong the band-pass mis-centres and the heading attenuates.

**If the LED spins fast / heading is wildly wrong ONLY in one orientation**, it's the spin-direction sign. `omega_from_accel` is an unsigned magnitude (the accel can't sense CW vs CCW), so the sign is taken from the magnetometer (`state.spin_rate_lp`). When the robot is **inverted** it spins the opposite way in the world frame; the mag catches this and `kf_omega` should flip sign within ~50 ms. Test BOTH orientations here (spin it upright, then flip it and spin again) — the LED must be stationary in both. If it's broken only when inverted, check that `mag_valid` uses `|kf_omega|` and that `spin_rate_lp` is taking the mag's sign (schema v4 fix).

### Pass criteria

- LED appears stationary (±5°) at 500+ RPM
- `est_theta` tracks with < 5° RMS error visible in graph
- No drift observed over 30 seconds of constant-speed spinning
- `est_omega` tracks `omega_from_accel` closely during steady-state spin (diverges during spin-up — expected)

---

## Level 5 — Full MELTY (Drift Tuning)

**Goal:** Robot translates reliably in commanded direction while spinning.  
**Setup:** Open floor, **props on**, safe area, full clearance.  
**Firmware environment:** `production` (bringup level 0)

**Only proceed to this level after Level 4 passes completely.** If the LED is not stationary, fix that first.

### Step 1: Flash production firmware

```bash
cd sunshine_brain && pio run --target upload --environment production
```

### Step 2: Confirm LED is stationary

At low spin throttle, verify the LED appears stationary at a fixed heading before attempting any translation. This confirms the Kalman filter is working.

> **A dead magnetometer now means MELTY WILL NOT SPIN UP — deliberate, not a fault.**
> MELTY commands pass through the wheel-speed cap (`melty_speed_cap()` in `control.c`),
> which clamps the mean wheel command to the no-load speed the *measured* body rate
> demands plus a fixed slip allowance. Its rate reference is the mag-driven `kf_omega`,
> and with no mag there is never a lock, so the reference falls back to
> `SUNSHINE_MAG_MIN_OMEGA` and the command sits at the unlocked ceiling (≈1194 DShot at
> 8.2 V) forever: the robot stalls out near 50–60 rad/s however far the throttle is
> pushed. The trade is intended — a MELTY robot with no heading reference is
> undriveable anyway — but it converts "degraded but spinning" into "will not spin up",
> so **suspect the mag first** when MELTY won't spin up while TANK is fine (the cap is
> MELTY-only, which is exactly why TANK still spins). Plot `real.kf_omega` against
> `input.ctrl_throttle`: `kf_omega` flat near the threshold while the throttle is high
> is this cap — not a motor, battery or ESC fault. Confirm with `real.mag_x_filt` /
> `real.mag_y_filt` (their magnitude collapses when the mag is dead), then go back to
> Level 4 Step 3 and fix the magnetometer.

### Step 3: Test translation in MELTY mode

In the host app:
1. Set mode to **MELTY** (green button)
2. Bring throttle up slowly with arrow keys until the robot is spinning steadily. Do not start near full throttle: MELTY translation uses the symmetric DShot headroom above and below the spin command, so very high throttle intentionally leaves little translation authority.
3. Press W briefly → robot should drift forward
4. Press A/D → robot should drift left/right
5. The direction the robot drifts should match the driver's reference frame (LED-defined forward = W)

> **Test right-side up.** If the robot is inverted, the world-frame spin reverses and
> the whole driver frame mirrors, so "W" appears to drive *away* from the LED — this is
> expected, not a phase bug (check `input.accel_z`: ≈ −20 counts means inverted). Only
> tune `DRIFT_PHASE_OFFSET_RADS` for a direction error seen **upright**.
>
> **Translate at a moderate spin, not maximum.** Two effects weaken translation at high
> RPM: shrinking DShot headroom *and* motor/ESC bandwidth (the wheels can't change speed
> fast enough — measured in the logs, and it also rotates the effective direction with
> speed). Bring throttle up only until the LED is steady and spin is stable.
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

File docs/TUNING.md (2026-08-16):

# Sunshine Tuning Guide

Tuning guide for the Kalman filter and MELTY drift profile. Read `FILTER_MATH.md` first if you want to understand why these parameters exist.

All constants are in `sunshine_core/include/sunshine_core.h`. Change them and rebuild. You can override them with `-D` flags in `platformio.ini` to try values without editing the source file.

---

## Kalman Filter Tuning

The Kalman filter estimates two states: `θ` (absolute angle, rad) and `ω` (angular velocity, rad/s). Four constants control how much the filter trusts each measurement source vs. its own predictions.

### Parameter Reference

| Constant | Default | Units | What it controls |
|---|---|---|---|
| `KF_Q_THETA` | 1e-6 | rad²/step | How much the filter expects θ to drift on its own between steps |
| `KF_Q_OMEGA` | 1e-2 | rad²/s²/step | How much ω is expected to change between steps |
| `KF_R_ACCEL` | 0.5 | rad²/s² | How noisy the accelerometer omega measurement is |
| `KF_R_MAG` | 0.01 | rad² | How noisy the magnetometer angle measurement is |

**Rule of thumb:** Q values control process noise (model uncertainty). R values control measurement noise. Higher R = trust the measurement less. Higher Q = assume the model drifts more = update faster.

### Tuning Procedure

Work through these steps in order. Do each at bringup level 4 (nav filter on, DShot zeroed). Use the host app graph panel — plot the channels mentioned.

#### Step 1: Tune omega (ω) tracking

Plot `vars.omega_from_accel` and `vars.est_omega` simultaneously.

**Spin the robot at a steady speed** (hand-spin or with a bench drill — props off). After spin-up settles (~2 seconds):
- `omega_from_accel` and `est_omega` should track closely
- During spin-up, `omega_from_accel` reads high (tangential acceleration inflates it — see FILTER_MATH.md). This is expected.

**If `est_omega` lags `omega_from_accel` during steady state:**
- Decrease `KF_R_ACCEL` (trust accel more) or increase `KF_Q_OMEGA` (assume ω changes more)

**If `est_omega` is too noisy / jumpy:**
- Increase `KF_R_ACCEL` (trust accel less)

**Typical good values:** `KF_R_ACCEL = 0.3–1.0` (the accel is the rate sensor at all times), `KF_Q_OMEGA = 5e-3–1e-2`

#### Step 2: Verify mag threshold

Plot `vars.mag_valid`. It should become 1 (true) at around 480 RPM (16π ≈ 50.3 rad/s). If the robot never crosses this threshold, check that `est_omega` is tracking correctly (Step 1). If the LED never locks while spinning fast, also check `input.mag_x/y` for a dead/frozen sensor (zero variance = no data) before touching thresholds.

The threshold is defined by `SUNSHINE_MAG_MIN_OMEGA = 16π rad/s` in `sunshine_core.h`. It's set by the spin-tracking band-pass (`mag_heading.c`): the band's lower edge is ≈ 0.75·spin-freq, and below ~8 Hz spin that edge sinks toward the slow average-ESC-current band (which the 2nd-order skirt no longer rejects well) and the tangential-accel inflation of `est_omega` grows. Hard-iron DC is killed at any speed by the band-pass's zero at DC, so it isn't what sets the minimum.

#### Step 3: Tune angle (θ) tracking

Plot `vars.est_theta`. With the mag filter active (above 480 RPM), θ should converge to a stable value rather than drifting. The open-loop mag heading is absolute, so it should not drift; a slow creep means the mag isn't trusted enough (decrease `KF_R_MAG`).

Also watch the LED: it should appear as a stationary dot at a fixed heading once the filter converges (~3-5 seconds after crossing the mag threshold).

**If θ drifts slowly over 30+ seconds:**
- Decrease `KF_R_MAG` (trust mag more) or increase `KF_Q_THETA` (allow angle to correct faster)

**If θ jumps/oscillates:**
- Increase `KF_R_MAG` (trust mag less)
- Increase `KF_R_ACCEL` to reduce omega noise feeding into theta via the covariance matrix

**If filter never converges (θ keeps sweeping):**
- Check `mag_x_filt` and `mag_y_filt` — these are the band-passed Earth-field axes; they *oscillate* at the spin frequency, but their magnitude `sqrt(x²+y²)` should be a steady ~18–22 µT. If the magnitude collapses, `omega_from_accel` is so far off that the spin frequency has fallen outside the ±33% tracking band (or the spin is below the 480 RPM threshold) — fix `est_omega`/`omega_from_accel` first (Step 1).

**Typical good values:** `KF_R_MAG ≈ 0.01` (open-loop mag is a clean absolute reference, so trust it), `KF_Q_THETA = 1e-7–1e-5`.

#### Magnetometer band-pass centre LP — `MAG_BP_FC_LP_HZ` (default 1.5 Hz)

The mag band-pass is centred on the spin frequency taken from `omega_from_accel`.
That accel rate wobbles at the spin frequency **while translating** (linear body
acceleration adds a once-per-rev term), and retuning the band-pass from the raw
instantaneous value makes it *time-varying*, which injects wobble into `mag_angle`.
`MAG_BP_FC_LP_HZ` low-passes the centre so the filter stays quasi-LTI. Measured on
real logs it cut the `mag_angle` rate-error ~65%. It is re-seeded below the mag-valid
threshold, so a fast spin-up (even right after an impact stops the robot) carries no
lag across the stop.

- **Raise it** (e.g. 3–5 Hz) to track spin-up faster, at the cost of rejecting less
  translation wobble.
- **Lower it** for a steadier centre but a laggier response to real rate changes.
- `spinup_lag.py` shows the true spin rate stays inside the ±33% pass band ~98.7% of
  the mag-valid time at 1.5 Hz; the residual is brief impact glitches (cutoff-
  independent), so 1.5 Hz is a good default.

#### Angular-rate source: accel magnitude + mag sign (v5 mag-rate REVERTED)

The Kalman rate comes from the **accel magnitude** (`omega_from_accel = √(a_c/r)`)
with the **mag's sign** (`state->spin_rate_lp` — the accel can't sense CW/CCW).

The v5 design instead drove the rate from the mag's own rotation rate while the mag
was valid, reasoning it is unbiased by linear acceleration during translation. That
was **reverted on the 2026-08-15 steel-arena log**: every venue measured so far has
AC magnetic interference tones inside the spin band (a ~9.77 Hz harmonic comb at
19.5/29.3/39.1/48.8 Hz — the 102.4 ms WiFi-beacon period — plus 50/100 Hz mains-like
tones, 2–7 µT; both home logs and the arena show them). An in-band tone beats
against the Earth line and wobbles `mag_angle` at |f_spin − f_tone| (3–13 Hz).
The angle update tracks that wobble roughly 1:1, but a *rate* derived from the angle
DIFFERENTIATES it — multiplying the wobble by the beat frequency — so the mag-rate
path amplified it into ±10–20 rad/s of `kf_omega` wobble: the arena's
"locks, bounces all over, locks" LED. Measured with the replay bounce metric
(2 s quadratic-detrend residual of `kf_theta`):

| config | arena stationary p50/p90 | home stationary p50/p90 | home translating p50 |
|---|---|---|---|
| v5 mag rate | 25.7° / 143.5° | 22.2° / 44.9° | 24.6° |
| accel rate + mag sign | **11.7° / 26.4°** | 21.3° / 43.9° | 24.8° |

The v5 translation benefit does not reproduce (the interference exists at home too);
the accel's once-per-rev translation wobble sits at the spin frequency where the KF
attenuates it, and its +2–12% Jensen bias is cancelled by the strong mag angle
anchor (`KF_R_MAG = 0.01` — measured ~8° steady innovation offset). Do NOT "fix"
LED wobble by raising `KF_R_MAG` above ~0.05: the weakened anchor lets the accel
bias walk the LED 50–100° off the field reference. `spin_freq_lp` is still used
only to centre the band-pass (loop-independent).

#### Step 4: Pass/fail check

At 500+ RPM, run the robot for 30 seconds:
- LED must appear stationary (not sweeping)
- `est_theta` RMS error vs. visual heading: < 5° (0.087 rad)
- `est_omega` matches `omega_from_accel` within 10% during steady-state spin

---

## MELTY Drift Tuning

MELTY mode applies a differential DShot command that changes with robot angle. The left and right wheels receive equal-and-opposite offsets around the base spin command, so the body keeps spinning while the average world-frame force points in the commanded direction.

### Parameter Reference

| Constant | Default | What it controls |
|---|---|---|
| `DRIFT_AMPLITUDE` | 0.40 | Max differential as a fraction of available symmetric DShot headroom. |
| `DRIFT_PLATEAU_WIDTH` | 0.35 | Fraction of full rotation spent at each +1 and -1 plateau. 0.35 gives two 126° plateaus and two 54° ramps. |
| `DRIFT_PHASE_OFFSET_RADS` | 0.0 | Fixed motor-timing offset between the LED/driver heading and the wheel-force waveform. |
| `DRIFT_PHASE_LEAD_S` | 0.018 | ESC/traction lag compensation. Added phase is `kf_omega * DRIFT_PHASE_LEAD_S`. **Measured, per-build** — `tools/replay/translation_lag.py`, procedure in BRINGUP.md Level 5 Step 4. |
| `THETA_RATE_RADS` | π rad/s | Heading offset rate per full left/right arrow deflection (ctrl_theta = ±127). |

### How the pulse works

At each tick, the robot's current angle relative to the commanded drive direction gives a `phase` value. A balanced bipolar trapezoid converts that phase to a differential multiplier:

```
+1.0     flat push
         ┌──────────────┐
 0.0  ───┘              └── ramps
                         ┌──────────────┐
-1.0                    flat pull/opposite side
      0                 pi              2pi
```

The waveform has zero mean over a revolution and satisfies `wave(phase + pi) = -wave(phase)`. That symmetry matters: the robot gets one push direction for half the cycle and the opposite wheel differential 180° later, instead of a one-sided bias that mostly loads one wheel.

`phase = robot_angle - drive_dir + DRIFT_PHASE_OFFSET_RADS + kf_omega * DRIFT_PHASE_LEAD_S`

`headroom = min(base - DSHOT_NEUTRAL, DSHOT_MAX - base)`

`diff = wave(phase) × drive_magnitude × DRIFT_AMPLITUDE × headroom`

`dshot_left  = base + diff`
`dshot_right = base - diff`

`headroom` prevents clipping. At low throttle there is little room above neutral; at very high throttle there is little room below max. Translation authority is strongest at moderate spin commands and intentionally fades near full throttle.

### Spin rate vs. translation authority (measured)

There are **two** reasons to translate at a *moderate* spin, not maximum:

1. **Headroom (control side):** the symmetric DShot headroom peaks at ~50% throttle
   and shrinks toward both extremes (above).
2. **Motor/ESC bandwidth (plant side):** the wheels can only change speed so fast.
   Measured from real logs (`tools/replay/erpm_bandwidth.py`), the achieved eRPM
   ripple per unit DShot ripple **falls as spin rises** (gain ~18 at 15 Hz spin →
   ~11 at 22 Hz), with a large phase lag. So at high RPM the once-per-rev modulation
   is increasingly attenuated *and* phase-shifted — translation gets weaker and its
   direction rotates with speed. Higher RPM buys gyroscopic stability but hurts
   translation authority; find the sweet spot experimentally.

### Translation force requires the wheel-speed cap (tire saturation)

Translation force is the *difference* between the two wheels' contact-patch friction
forces, and friction saturates at ~µN within a few tenths of a m/s of slip. Measured
on the pre-cap translation2 log: both wheels carried **+0.7 to +3.7 m/s of constant
forward slip**, and the drift-wave modulation (±0.1–0.9 m/s realized) never brought
either wheel near zero slip — so both tires sat pinned at saturated µN all
revolution and the differential force was ~zero *regardless of the commanded
waveform*. Symptom: motors audibly modulate, eRPM visibly modulates, robot barely
moves and wobbles inconsistently (the residual forces are normal-load fluctuations,
not the drift wave). The wheel-speed cap fixes this as a side effect of fixing the
bounce: it pins mean slip under `WHEEL_SLIP_ALLOW_MS` (5.0 m/s max), so the drift wave now
swings the retreating wheel down through zero slip into braking — one wheel
saturated forward, the other near-zero/braking = a real once-per-rev force
differential. Consequence: **do not "fix" weak translation by disabling or loosening
the cap** — that removes the very condition translation needs.

### `DRIFT_PHASE_LEAD_S` from the eRPM lag

The DShot→eRPM lag above turns into a heading-referenced phase error `omega × lag`
that grows with spin rate — exactly what `DRIFT_PHASE_LEAD_S` compensates.

**Measure it, don't guess it:** `tools/replay/translation_lag.py <log.sun>` cross-
correlates the logged DShot differential against the eRPM differential over every
translation window and prints the recommended constant (full procedure: BRINGUP.md
Level 5 Step 4). Unlike single-frequency demodulation (`erpm_bandwidth.py`) the
time-domain cross-correlation is not ambiguous modulo one rotation, and the script's
constant-offset residual check separates lag from a `DRIFT_PHASE_OFFSET_RADS` problem.

**Measured (2026-07-20 translation2 log):** a pure **time delay of ~20 ms** (18–24 ms
over 24 windows), identical for both spin directions, with **no constant offset** (so
`DRIFT_PHASE_OFFSET_RADS` stays 0 — the phase convention is correct). Subtracting the
~3 ms median-5 eRPM telemetry lag leaves **~17 ms of physical actuation delay** →
`DRIFT_PHASE_LEAD_S = 0.018f`. Uncompensated, this was a 110–150° force-direction
error at 1000–1300 RPM — the wheel-speed peak landed nearly opposite the commanded
direction, which is why the robot wobbled and barely translated. Confirm the residual
direction error on hardware (position cannot be replayed from logs) and refine with
the two-speed method in Step 3 below.

### Inverted operation flips the apparent translation direction (not a bug)

If the robot is **upside down**, its world-frame spin reverses (the schema-v4 spin-sign
recovery handles this, so `kf_omega` reads negative and the LED still tracks). But the
whole driver frame is mirrored, so "W" appears to drive *away* from the LED. This is
expected — verify direction **right-side up**. Tell inversion from the logs by
`input.accel_z` sign (≈ +20 counts upright, ≈ −20 inverted).

### Tuning Procedure

Do this at bringup Level 5 (production firmware, props on, open floor).

#### Step 1: Confirm LED is stationary

Do not begin drift tuning if the LED is sweeping. Fix Kalman tuning (Level 4) first.

#### Step 2: Set baseline throttle

In MELTY mode, bring throttle up slowly with arrow keys until the robot spins at a consistent speed with the LED appearing stationary. This is your tuning throttle. Hold it there throughout tuning.

#### Step 3: Test forward translation

Press W briefly. The robot should drift forward (toward the LED heading when W is pressed).

**If the robot barely moves:** First make sure throttle is not near max, because headroom shrinks there. If direction is repeatable but weak, increase `DRIFT_AMPLITUDE` (e.g. 0.40 → 0.55).

**If the robot moves sideways or backwards:** If the LED is stationary, tune `DRIFT_PHASE_OFFSET_RADS`. Start with 15-30° steps (`0.26f` to `0.52f` rad). If a positive change makes the direction worse, use the opposite sign.

**If the direction is correct at one RPM but wrong at another:** Tune `DRIFT_PHASE_LEAD_S`. A time lag turns into phase error as `omega * lag`; at 240 rad/s, 1 ms is about 14°. Estimate the needed lead from two speeds:

`DRIFT_PHASE_LEAD_S ≈ (offset_high - offset_low) / (omega_high - omega_low)`

**If the robot translates too aggressively and loses spin speed:** Decrease `DRIFT_AMPLITUDE`. The controller now scales by available DShot headroom, but large differential still modulates traction and spin energy.

#### Step 4: Test all four directions

Test N/S/E/W at the same throttle level. Pass if all four directions produce consistent, controllable translation in the correct direction.

#### Step 5: Tune waveform shape (optional)

If translation is jerky or inconsistent, adjust `DRIFT_PLATEAU_WIDTH`:
- Higher values, up to about `0.45`, give longer max-output dwell and behave more like a rectangle.
- Lower values, down toward about `0.25`, widen the ramps and are gentler for the ESC/wheel.
- Keep the waveform balanced; do not reintroduce unequal positive/negative dwell.

#### Step 6: Heading rate

`THETA_RATE_RADS` controls how fast the driver's heading reference rotates when holding left/right arrows. At the default (π rad/s), full deflection rotates the heading 180°/second.

Increase if the driver needs to re-orient heading quickly. Decrease if small arrow taps cause too much heading drift.
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

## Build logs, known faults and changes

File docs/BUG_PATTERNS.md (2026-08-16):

# Bug Patterns

Recurring categories of bugs found during the May 2026 code review. Use this as a checklist when auditing new code.

---

## 1. Physics / Domain Model Wrong

Code compiles and runs but the underlying model of the hardware is incorrect.

**Examples found:**
- TANK mode control formula: `L = fwd+turn, R = fwd-turn` — for tangential wheels, same-direction motors spin the body; opposite-direction motors translate it. The formula was backwards: W caused body spin instead of forward translation.
- `motor_tick` clamped `omega` to `≥ 0` with `.max(0.0)` — AM32 3D mode supports bidirectional operation; reverse commands always produced zero omega.
- `dshot_to_throttle(0.0)` returned `-1.048` (full reverse) — DShot values 0–47 are special commands / disarmed, not valid throttle. Missing `if d < DSHOT_MIN { return 0.0; }` boundary check.

**Where to look:**
- Any place a physical quantity is mapped, scaled, or clamped: check the hardware datasheet or DShot spec matches the code's assumptions.
- Motor direction / sign conventions: define positive once and audit every place it appears.
- Boundary conditions at neutral / zero: off-by-one errors are common at the boundary between forward, neutral, and reverse.

---

## 2. Data Model Confusion (What's computed where)

The codebase has three distinct data origins — hardware inputs, received state, and host-computed variables. Code that confuses these categories produces silently wrong or permanently-zero values.

**The model (from ARCHITECTURE.md):**
- `SunshineInput` — raw sensor frames from hardware, received at 1 kHz (50 Hz over the wire as 20-input batches)
- `SunshineState` — Kalman filter state from the brain, transmitted in every 50 Hz telemetry frame
- `SunshineVars` — **never telemetered**, always recomputed on host via `brain_step()`

**Examples found:**
- `frame.state` (the received `SunshineState`) was never stored in `DataPoint` — discarded in `ingest_frame`. The "State (real)" UI group was permanently zeros because it read `real_vars`, which was only populated for log-file replay.
- `real_vars` was labeled "real" but was zero for all live and simulation data. The distinction between "replayed" and "real" vars made no sense for the live use case.
- `heading_deg` was placed in the "State" UI group; it is host-computed from state, so it belongs in Variables.
- `rep.est_theta` / `rep.est_omega` were in "State (replayed)" — they are host-computed variables, not received state.
- Wall-clock timestamps were used instead of hardware timestamps (fixed in a8f687f: `now_us()` → `expand_hw_time(input.time_us)`).

**Where to look:**
- Any new channel added to the graph: ask "is this received from hardware, or computed on host?" Use `hw.*` for received state, `rep.*` for host-computed, `input.*` for raw sensor frames.
- Anywhere `DataPoint` fields are read: confirm the field is actually populated for the source you care about (live / sim / replay).
- Any new field on `SunshineVars`: verify it is not being confused with `SunshineState`.

---

## 3. Resource Lifecycle Bugs

Objects that hold OS resources (threads, file handles, sockets) dropped without cleanup.

**Examples found:**
- `connect_serial` assigned the returned `SerialConnection` to `let _conn` — Rust drops it immediately at end of scope, but the background reader thread continued running (held its own `Arc`). `disconnect_serial` was a documented no-op. Reconnecting leaked a thread every time.
- `LogWriter::close()` was never called — the `logging_complete` flag at byte offset 28 was never written to `1`, so every log file appeared incomplete to readers.
- Both cases shared the pattern of a method that **must** be called for correctness but had no enforcement.

**Where to look:**
- Any struct with a `close()` / `shutdown()` / `stop()` method: implement `Drop` to call it, or audit every code path that discards the struct.
- Any `let _x = expensive_constructor()` — the leading `_` signals intentional discard in Rust, which is almost never correct for resource-holding types.
- Async tasks spawned with `tokio::spawn`: confirm the stop signal is reachable from all exit paths.

---

## 4. Silent No-ops (Feature Stubs Never Wired Up)

Code that compiles, appears functional, but does nothing.

**Examples found:**
- `read_frame()` in `replay.rs` existed but no Tauri command ever called it — the replay tab showed metadata but never played frames back.
- `disconnect_serial` contained only a comment: `// Connection dropped when SerialConnection is not stored; extend AppState if needed`.
- The `real_vars_snap: Option<&SunshineVars>` parameter was passed as `None` everywhere for live and sim, making the entire `real_vars` path in the pipeline dead code for those sources.

**Where to look:**
- Every Tauri command in `commands.rs`: does it actually do what its name says? Verify the happy path end-to-end.
- Every `Option` parameter: check all call sites for `None` — if all callers pass `None`, the `Some` branch is dead.
- UI buttons/tabs: manually trace from click handler → invoke → command → effect. A button that calls an invoke with no backend handler fails silently.

---

## 5. Kalman Filter Initial Conditions and Thresholds

The filter has structural behaviors at initialization and at low-speed edge cases that are easy to miss without running it against real data.

**Examples found:**
- `kf_P[3]` (omega variance) initialized to `100.0` — std dev of 10 rad/s, far too high. First accelerometer measurement jumped omega to ~7.8 rad/s.
- `omega_from_accel` is computed as `sqrt(centripetal / r)`. Below ~7.8 rad/s the centripetal acceleration is less than 1 ADXL count, so `omega_from_accel = 0` and `kalman_update_omega` is skipped. With no drag in the predict step, `kf_omega` gets stuck at the last measured value until the robot spins up again.

**Where to look:**
- `sunshine_state_init`: initial `kf_P` values control how aggressively the filter trusts its first measurement.
- Any `if condition { kalman_update_*() }` guard: consider what happens to the estimate when the condition is permanently false (e.g., robot at rest, saturated accelerometer, spinning below mag threshold).
- Quantization thresholds: any sensor with integer counts has a minimum detectable signal. Compute it and document when the filter goes open-loop.

---

## 6. Trusting a Sensor Without a Health Check

A gate that decides *when* a sensor is usable is not the same as a check that the
sensor is *alive*. Data can be structurally present (fresh packets, plausible-range
values) while carrying no information.

**Examples found:**
- 2026-08-15 steel-arena log: the LIS3MDL output froze at one constant (x,y,z)
  from boot for ~160 s (recovered after a flip impact). `mag_valid` only gated on
  spin rate, so the band-pass reduced the constant to ~0.1 µT of numerical noise
  and the Kalman tracked `atan2(noise)` as an absolute heading at full `KF_R_MAG`
  weight — the robot could not lock at all, and `kf_omega` was dragged ~60 rad/s
  off the true rate. (No automated gate was added — kept simple by choice; the
  check is manual: zero variance on `input.mag_x/y` = dead sensor.)

**Where to look:**
- Every sensor consumed by the filter: what does the pipeline output when the
  sensor returns constants? Zeros? Full-scale rails? Would any downstream flag
  actually drop?
- Validity flags derived only from *other* quantities (speed, mode, time) rather
  than from the sensor's own signal quality.
- Drivers that return a struct with `.valid = true` hardcoded.

---

## General Checklist for New Code

1. **Physics**: Can you trace every sign, scale factor, and direction convention to a hardware spec or measured value?
2. **Data origin**: Is each channel tagged with what produces it (hardware-received vs host-computed)?
3. **Resources**: Does every resource-holding struct have a `Drop` impl or an audited caller that always cleans up?
4. **Feature completeness**: Does the UI action trace all the way to a real effect? Test by clicking it.
5. **Filter edge cases**: What does the filter output when the robot is at rest? Spinning below each threshold? At maximum speed?

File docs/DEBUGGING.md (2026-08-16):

# Debugging with Replay

Instructions for the `sunshine:replay-debug` Claude skill. Use this skill when you have a `.sun` log file and want to debug filter behavior, investigate unexpected robot behavior, or tune parameters using real recorded data.

---

## What the replay-debug skill does

The skill loads a `.sun` log file, replays all 1 kHz sensor frames through `sunshine_step()` (the same C code that ran on the robot), and lets you inspect any variable at any time. Because replay is deterministic — identical inputs + state → identical outputs — you can change tuning parameters and re-run to see exactly how the filter would have behaved.

---

## When to use it

- **Filter not converging:** LED sweeping, `est_theta` drifting, mag update not helping
- **Unexpected DShot outputs:** Robot not translating in expected direction, one ESC saturating
- **Spin-up anomalies:** `omega_from_accel` too high during spin-up, accel saturation flags firing unexpectedly
- **Investigating a specific event:** "At t=12.4s the robot suddenly changed direction — what happened to the filter?"
- **Parameter tuning without hardware:** Try different `KF_R_ACCEL`, `KF_R_MAG`, `DRIFT_AMPLITUDE` values on recorded data

---

## Log file location

Log files are written by the host app to:
```
~/Documents/sunshine_logs/YYYY-MM-DD_HH-MM-SS[_label].sun
```

**On this machine that is literally `~/Documents/sunshine_logs`** — the logs are large and
machine-local, so they are outside the repo and nothing in the tree references one by
path. Anything you are asked to investigate ("the translation log", "the run that
bounced") is a file in there. The host app also shows the current log file path in the
logging status bar.

The name starts with a zero-padded sortable timestamp, so the newest log is the last one
lexicographically — but **select by mtime**, because a session that is still recording (or
that crashed) keeps its original name while the file keeps growing:

```bash
ls -t ~/Documents/sunshine_logs/*.sun | head -1           # newest
LOG=$(ls -t ~/Documents/sunshine_logs/*.sun | head -1)    # ...and use it
build/replay "$LOG" > cont.csv
```

If the newest log's header `flags` bit0 (`logging_complete`) is clear it was never closed
cleanly — normal while the app is still running. It replays fine; the harness reads whole
frames only, so a torn trailing frame is simply dropped.

---

## Log file format (for reference)

**Current format is FILE_FORMAT_VER 3 (95-byte header), schema v5.** `sizeof_state`
and `sizeof_input` are read from the header, so the file format is unchanged when a
struct grows — only the schema_version bumps. Readers must still handle VER 2 (one
state + a vars block) and VER 1 (93-byte header) for old logs, AND any older
sizeof_state (schema v4 = 52, v3 = 44, v2 = 60) — always use the header's sizeof,
never a constant. **Schema v5 also widened `batt_offset` int8→int16** (a mid-struct
resize), so the input reader is schema-aware: pre-v5 logs (`schema_version < 5`,
`sizeof_input` 29) use the old int8 layout with `mode`/`dshot_*_q` one byte earlier,
and the old int8 battery LSB is remapped to the v5 int16 scale (×20.5). See
`replay.rs::read_input` / `replay.c::unpack_input`.

```
Header (95 bytes, FILE_FORMAT_VER 3):
  magic[5]        = "SHINE"
  file_format     = 3 (uint16 LE)           ← 2 in older files
  header_size     = 95 (uint16 LE)          ← was 93 in VER 1
  schema_version  = uint32 LE               (bumped when structs change; 5 now)
  sizeof_input    = 30 (uint16 LE)          ← schema v5 (was 29; batt_offset int8→int16)
  sizeof_state    = 56 (uint16 LE)          ← schema v5 (was 52 in v4, 44 in v3, 60 in v2); see SunshineState
  sizeof_vars     = 0  (uint16 LE)          ← VER 3: NO vars block (was 56 in VER 2)
  created_at_ms   = Unix timestamp ms (uint64 LE)
  source          = 0=live, 1=replay, 2=simulation (uint8)
  flags           = bit0=logging_complete (uint8)
  label[64]       = null-terminated UTF-8
  num_inputs      = uint16 LE               ← inputs per frame (20)

Frame (717 bytes at num_inputs=20, schema v5): VER 3 carries TWO states, no vars
  frame_id         = uint32 LE, monotonic (gaps = dropped telemetry)
  frame_flags      = uint8
  SunshineState    = 56 bytes  (REAL state at the START of the frame)
  SunshineState    = 56 bytes  (REAL state at the MIDPOINT input → 100 Hz state)
  SunshineInput×20 = 600 bytes (20 consecutive 1 kHz inputs, 30 B each)
```

Two state snapshots per 50 Hz frame give the **real filter state at 100 Hz**.
**Vars are NOT logged** — they are a pure function of (state, inputs); the host
recomputes them for a *replayed* series (filter free-running at 1 kHz from the
first frame). The *real* series is emitted **only at the two 100 Hz snapshots per
frame** (frame start + midpoint) and drawn as straight lines between them — a
*coarse* version of the replayed curve, not a fabricated 1 kHz staircase (the old
held-and-re-stepped approach produced steps plus per-tick noise and matched the
replayed dot count; see `pipeline.rs` `real_valid`). The brain sends one 50 Hz
packet per 20 inputs over **ESP-NOW v2** (715-byte payload = 3 + 2×56 + 20×30 at
schema v5; ESP-NOW v2 / IDF ≥ 5.4 is required for the >250-byte payload).

**Frame size formula:** `5 + sizeof_state × num_states + sizeof_input × num_inputs + sizeof_vars`
where `num_states = 2` for VER ≥ 3 else 1, and `sizeof_vars = 0` for VER ≥ 3.
Always read `num_inputs` from the header (bytes [93..94]) — do NOT hardcode it.

**VER 2 (legacy) frame** for reference: `frame_id(4) + flags(1) + SunshineState(60)
+ SunshineInput×N + SunshineVars(sizeof_vars)` — one state, a trailing vars block.

**SunshineVars field order** (56 bytes packed) — recomputed by the host, **not
stored** in VER 3 logs (kept here as the struct reference):
```
float  omega_from_accel, mag_x_filt, mag_y_filt, mag_angle, est_theta, est_omega,
       dshot_cmd_left, dshot_cmd_right, batt_voltage, erpm_left, erpm_right,
       centripetal_ms2;     ← 12 floats = 48 bytes
uint8  led_on, accel_saturated, mag_valid, loop_overrun;  ← 4 bytes
float  heading_deg;         ← 4 bytes (added in schema v2)
```

---

## Channels available for plotting / inspection

The host app channel selector groups channels into **Inputs**, **Variables**,
**REAL**, and **REPLAYED**:

- **REAL** (`real.*`): the **logged real state**, sampled at the two 100 Hz
  snapshots per frame and drawn as straight lines between them (coarse). This is the
  ground truth the robot recorded; `real.*` vars at a snapshot = one `sunshine_step`
  from that snapshot's state. It stays honest when the code changes and reads
  distinctly (coarse) from the smooth 1 kHz replayed curve.
- **REPLAYED** (`rep.*`): a filter free-running continuously at 1 kHz from the first
  frame via the *current* `sunshine_step`. Diff it against `real.*` to see the
  effect of a code/tuning change, or to view the 1 kHz detail between snapshots.
- **VARIABLES** (`var.*`): quantities that are a pure function of the **inputs only**
  (no filter state), so real and replayed are identical — one shared 1 kHz series.

**Inputs (1 kHz, shared — raw sensor data):**
- `input.accel_x/y/z` — raw ADXL375 counts
- `input.mag_x/y`, `input.mag_magnitude` — raw LIS3MDL counts / µT
- `input.erpm_left/right` (raw f16), `input.ctrl_x/y/theta`, `input.ctrl_throttle`
- `input.rssi`, `input.batt_offset` (int16 LSB, schema v5)

**Variables (1 kHz, shared — derived from inputs, no real/replayed split):**
- `var.omega_from_accel` (rad/s), `var.centripetal_ms2` (m·s⁻²)
- `var.accel_x/y/z_ms2` (m·s⁻²) — raw counts × ADXL scale
- `var.batt_voltage` (V), `var.erpm_left/right` (RPM)

**REAL state + vars** (`real.*`) — and the identical set under **`rep.*`** (these
depend on filter STATE, so they differ between the recorded run and a re-run):
- State: `kf_theta` (rad), `kf_omega` (rad/s), `theta_offset` (rad)
- Vars: `heading_deg`, `mag_angle`, `mag_x_filt`, `mag_y_filt`, `dshot_left`,
  `dshot_right`

So e.g. `real.dshot_left` vs `rep.dshot_left` compares the real motor command to
what the current code would output; `real.kf_theta` vs `rep.kf_theta` shows
heading-estimate divergence. Battery / eRPM / ω-from-accel / centripetal moved to
`var.*` because they're input-only (identical real vs replayed).

**Offline `replay.exe` CSV columns** (single series; see the harness section
below): `time_us, mode, ctrl_x, ctrl_y, ctrl_theta, ctrl_throttle,
input_dshot_l, input_dshot_r, input_dshot_l_q, input_dshot_r_q, kf_theta,
kf_omega, omega_accel, mag_angle, est_theta, est_omega, mag_x_filt, mag_y_filt,
heading_deg, led_on, mag_valid, accel_sat, dshot_l, dshot_r,
erpm_left, erpm_right, mag_x, mag_y, accel_x, accel_y, theta_offset,
stored_kf_theta, stored_kf_omega,
stored_theta_offset` and (VER 2 logs only, at frame-end rows)
`stored_est_theta, stored_mag_angle, stored_led_on`.
`stored_kf_theta/omega/theta_offset` are sparse: in VER 3 logs they are present
only on the rows corresponding to the frame-start and midpoint state snapshots.

### Interpreting eRPM — NaN means "not measurable", not "stopped"

Bidirectional-DShot eRPM is derived from the ESC's **own commutation timing**. Below
~5 % duty AM32 turns the FETs off and lets the motor coast, so there is nothing left to
time and the ESC emits a decaying, meaningless period. The firmware therefore reports
**NaN** whenever the previous tick's duty was below the commutation threshold, and the
graph draws that as a **gap**. Read it as *"the ESC was not commutating"* — the wheel
may well have been spinning fast.

`0` now means what it says: a genuinely stopped wheel. **Logs recorded BEFORE this change
encode unmeasurable as 0, not NaN** — every undriven sample in them was written as a hard
0, which is why old eRPM traces "drop to zero" for long stretches. There is no way to
recover the distinction after the fact in such a log; read its zeros as "unknown".

That the zeros were never real is measurable two ways in
`2026-07-20_04-20-24_translation2.sun`:

- **Prevalence.** 77.6 % of samples with the command at neutral read zero, against 0.01 %
  of driven samples. Zeros track *the command*, not the wheel.
- **The coast-down at t = 402.9 s**, which settles it outright. The command drops to 0
  while `real.kf_omega` stays flat at −94 rad/s, so the flywheel — and therefore the
  wheels — provably cannot have slowed, yet `erpm_left` "falls" 18416 → 3312 over ~120 ms
  and throws a 25504 spike on the way down. The wheels were still turning at ~11 500 eRPM
  throughout. All of it is decode garbage from a coasting ESC.

Practical notes:

- **Gaps in `var.erpm_left/right` are expected** at neutral and during the low half of
  the MELTY drift wave. Long gaps *while the throttle is up* are not — check the DShot
  command (`real.dshot_left/right`) actually left the commutation threshold.
- **A flat line with no gaps at all** across a neutral stretch means you are looking at
  a pre-NaN log (or the fake-zero path came back).
- `var.erpm_*` is the sanitised value (range gate against a command-derived ceiling,
  direction-aware deviation gate, median-5). `input.erpm_*` is the raw decoded float16
  — use it to see what the ESC actually reported before filtering.
- eRPM is **telemetry only**; nothing in the Kalman or control path reads it, so a bad
  eRPM stream cannot itself have caused a behaviour you are chasing.

---

## Common debugging scenarios

### Scenario 1: LED sweeping — theta not locking

**FIRST check spin DIRECTION (schema v4 fix).** `omega_from_accel = √(a_c/r)` is an
unsigned MAGNITUDE — the accel cannot tell CW from CCW. When the robot is **inverted**
(flipped: same chassis spin, opposite world spin), the magnetometer sees the reversed
rotation but the accel doesn't, so a heading slaved only to the accel counter-rotates
against the field at ~2× the spin rate (a total smear). Fix (`brain.c` + `mag_heading.c`):
the spin SIGN is taken from the mag rotation sense (`state.spin_rate_lp`) and copied onto
`omega_from_accel`; `mag_valid` uses `|kf_omega|`. Symptom of a regression here: `kf_theta`
winding opposite to the raw-mag field. Verify in replay that the LED heading rate matches
the raw-mag winding for BOTH orientations (drive the robot inverted in a test log).

**SECOND check the mag is ALIVE.** In the 2026-08-15 steel-arena (Nem) log the
LIS3MDL froze at one constant raw (x,y,z) from boot for ~160 s (it resumed after a
flip impact — suspected sensor hang or marginal power-up). A frozen sensor
band-passes to ~0.1 µT, and `atan2` of that noise is a garbage absolute heading —
zero lock, `kf_omega` dragged ~60 rad/s off truth. There is deliberately NO
firmware health check (kept simple); diagnose it MANUALLY in one line:
`input.mag_x/y` with zero variance over seconds = dead sensor (a live one has
~6 counts RMS noise even at rest). Power-cycle / reflash to recover.

**Steel arena note.** A steel floor/walls shunt and bend the local field: the
recovered Earth amplitude drops (measured 5.4–34 µT across one arena vs a steady
18–22 µT on open ground) and the field DIRECTION varies with position, so the
locked heading slowly rotates as the robot moves around the arena. That is
physics, not a filter bug — the mag can only lock to the local field. Expect the
driver to re-trim heading with arrow keys as the robot changes position; verify
health by checking `sqrt(mag_x_filt^2+mag_y_filt^2)` stays well above zero.

**THIRD check for in-band AC interference (the "locks, bounces, locks" pattern).**
FFT the raw `mag_x/z` over a stretch where the robot is DISABLED and stationary:
every venue measured so far shows a harmonic comb at 19.5/29.3/39.1/48.8 Hz
(multiples of 9.77 Hz = the 102.4 ms WiFi-beacon period — near-field TX current
bursts, not RF) plus 50/100 Hz tones, at 2–7 µT. A tone inside the band-pass
(±33% of the spin frequency) beats against the Earth line and wobbles `mag_angle`
by ~atan(A_tone/A_earth) at |f_spin − f_tone| — up to ±30° at 3–13 Hz in the
2026-08-15 arena, where the steel had also shunted the Earth line to 10–16 µT.
This is why the Kalman rate comes from the ACCEL (immune) and only the SIGN from
the mag — see TUNING.md "Angular-rate source". Residual LED wander scales with
A_tone/A_earth, so it is worst where the arena field is weakest, which also makes
the bounce position-dependent. Mitigation beyond the rate revert: spin at a rate
whose ±33% band dodges the strongest tones, or increase spin so the fractional
band clears the comb's strong low members.

**What to look at:**
1. `vars.mag_valid` — is it staying 1? If it drops, omega fell below the mag threshold (480 RPM).
2. `vars.est_omega` vs `vars.omega_from_accel` — does omega track (same sign)? `state.spin_rate_lp` sign = mag-derived spin direction.
3. `vars.mag_x_filt` and `vars.mag_y_filt` — the band-passed Earth sine; their magnitude `sqrt(x²+y²)` should be a steady ~18–22 µT. If it collapses, the spin is below the mag threshold, or `omega_from_accel` is so far off that the spin frequency has fallen outside the ±33% tracking band.
4. `state.kf_P[0]` — is the angle covariance decreasing? It should drop from 100 toward near-zero after the mag update engages.

**Try:** Set `KF_R_MAG` lower and replay. Does theta converge faster?

**Heading PRECESSION (LED rotates slowly) — the band-pass must be centred on
`omega_from_accel`, NOT `kf_omega`.** Root cause history: an earlier *closed-loop*
synchronous demodulator derotated by `kf_theta`; a later revision used an
open-loop band-pass but still took its centre frequency from `kf_omega`. Because
the band-pass output feeds `kf_omega` back, the per-tick coefficient retuning from
that fed-back rate **parametrically false-locked the recovered heading at half the
true spin rate** (sim: true 201.7 rad/s → 108.6; `kf_theta` a curvy, not straight,
sawtooth). The fix (implemented): `mag_heading.c` centres the band-pass on
`omega_from_accel`, which is a direct accel measurement **independent of the
estimate**, breaking the loop. The accel is therefore trusted fully for the rate
again (`KF_R_ACCEL` always — the old `KF_R_ACCEL_LOCKED` down-weighting is gone),
so `kf_omega` tracks `omega_from_accel`. Measure with `analyze.py precession` (raw
mag = filter-independent ground truth): the LED rate should match the raw-mag rate,
and the band-passed field magnitude should be a steady ~18–22 µT.

**What to expect from real vs. simulated mag data:**
- Real `inputs.mag_x/y`: large constant offset (~−95 µT X, ~+103 µT Y from motor hard-iron) plus a ~25 µT Earth-field sine wave. The LIS3MDL y-axis is physically inverted on the PCB, so `my = −E·sin(φ−θ)` (negated relative to the naive model). This is what the `-my_hp` in the heading `atan2` accounts for (`mag_heading.c`) — do not "fix" it.
- Sim `inputs.mag_x/y`: same convention with hard-iron and horizontal-only Earth field (25 µT, not 50 µT total).

### Scenario 2: omega_from_accel reads wrong

**What to look at:**
1. `vars.accel_saturated` — if this is 1 at unexpectedly low speeds, check IMU calibration or wiring.
2. `inputs.accel_x` and `inputs.accel_y` during steady spin — both should have similar magnitude if IMU is at 45°. If one dominates, IMU angle may be off.
3. `vars.centripetal_ms2` — at 500 RPM: `ω² × r = (52.4)² × 0.011 ≈ 30.2 m/s²`. Check if this matches.

### Scenario 3: DShot commands wrong in MELTY

**What to look at:**
1. `inputs.ctrl_x/y/theta` — are the driver inputs what you intended?
2. `vars.dshot_cmd_left` vs `vars.dshot_cmd_right` — plot together. In MELTY with forward input (ctrl_y > 0), the two signals should alternate: left high when pointing forward, right high when pointing backward.
3. `state.theta_offset` — if this has accumulated from left/right arrow presses, the heading reference is rotated.
4. `vars.est_theta` — check the angle was valid during the manoeuvre.

### Scenario 4: Accel saturation anomaly

**What to look at:**
1. `vars.centripetal_ms2` vs time — plot with the saturation threshold line at `280 × 9.81 = 2746.8 m/s²`
2. `vars.accel_saturated` — note how long it stays high
3. At what RPM does saturation occur? Expected: ~4800 RPM. If it saturates at lower speeds, check that the IMU is reading correctly (accel_z at rest should be ≈ +20 counts, not ≈ 0).

### Scenario 5: Wheel overspeed / the robot bounces while spinning

Symptom: in MELTY the robot hops vertically instead of sitting flat. One measurable
cause is the wheels spinning far faster than the ground demands: each landing dumps the
surplus wheel kinetic energy in as an impulsive traction spike, which throws the robot
back into the air.

**The reference figure: 123 eRPM per rad/s of body rate.** With no slip the wheel rate
is pure geometry, `ω_wheel = |ω_body| × WHEEL_CENTER_M / WHEEL_RADIUS_M`, and the ESC
reports electrical rpm, so

```
eRPM_no_slip = |ω_body| × (0.0405 / 0.022) × 60/(2π) × 7  =  123.06 × |ω_body|
```

**What to look at:**
1. Plot `var.erpm_left` and `real.kf_omega` together and divide: at 100 rad/s expect
   ~12 300 eRPM. A ratio much above 1.0 is overspeed — the evidence log
   `2026-07-20_04-20-24_translation2.sun` sat at a median 1.30 and a p95 of 2.27.
2. The ratio has a hard physical **floor at 1.0** (a wheel cannot roll slower than the
   ground unless it is braking). If the measured floor is not within a few percent of
   1.0, your `WHEEL_RADIUS_M` / `WHEEL_CENTER_M` / pole-pair constants are wrong — fix
   the geometry before reading anything else into the ratio.
3. `real.dshot_left/right` vs `rep.dshot_left/right` shows what the wheel-speed cap
   would have done to a run recorded before it existed.
4. `tools/replay/wheel_slip.py` reports commanded vs. capped DShot and the resulting
   slip distribution over a whole log — use it to confirm or adjust
   `WHEEL_SLIP_ALLOW_MS` against real data rather than argument.

**What the ratio should look like once the cap is in.** Note first what replay can and
cannot tell you here: replaying an old log through the capped `control.c` recomputes the
*command*, but the eRPM in that log is still the uncapped run's wheel response. A true
post-cap ratio distribution can only come from a log recorded with the cap live. (What
*is* measurable on an old log is the commanded no-load speed over rolling speed — that
modelled ratio falls from a 1.63 median / 5.51 p95 to 1.30 / 2.46 on the evidence log,
an ~83 % cut in squared excess wheel speed, the stored-energy proxy that lands as an
impulse on touchdown. It is a statement about the command, not about the wheel.)

What the cap does guarantee is a per-rate ceiling. Unloaded — airborne, the case that
matters — the wheel reaches the commanded no-load speed, which is rolling speed plus the
allowance, so:

```
ratio <= 1 + WHEEL_SLIP_ALLOW_MS / (|w_body| * WHEEL_CENTER_M)
```

| body rate | 50 rad/s | 100 rad/s | 150 rad/s |
|---|---|---|---|
| ceiling at allow = 1.0 m/s | 1.49 | 1.25 | 1.17 |
| ceiling at allow = 5.0 m/s (**shipping**) | 3.47 | 2.23 | 1.82 |

Two things legitimately sit above that line and neither is a fault: the drift wave rides
above the capped `base` (that asymmetry *is* translation), and below the mag-lock
threshold the cap holds a fixed ceiling while the rolling term keeps falling, so the ratio
at very low spin is large by construction — at 20 rad/s the ceiling is ~3.8. Judge the
ratio only above lock. A surviving 2×+ tail at 100 rad/s or more means the cap is not
being applied: check the mode is MELTY (TANK is uncapped by design) and check
`var.batt_voltage` per the note below.

The bind statistics below were measured at `WHEEL_SLIP_ALLOW_MS = 1.0`; the build now
ships 5.0 (see BRINGUP.md "Wheel slip threshold"), so the cap binds on materially fewer
samples — re-run `wheel_slip.py` rather than trusting these percentages.

At `WHEEL_SLIP_ALLOW_MS = 1.0` the cap binds on ~76 % of driven MELTY samples, and the
amount it removes shrinks with spin rate — median ~170 DShot counts below 50 rad/s, ~68
between 50 and 100, ~25 between 100 and 150 — because the rolling term grows while the
fixed allowance does
not. A cap that binds hard at high rate is the anomaly worth chasing, not one that binds
often at low rate.

**Remember the cap needs the battery.** The ESC is an open-loop voltage source, so
wheel speed is set by `duty × V_batt`; the pack moved 7.80–8.39 V inside a single run.
If `var.batt_voltage` is implausible (< 5 V or > 10 V) the cap fails open by design —
check it before concluding the cap is not working.

---

## Re-running with different parameters

To test a parameter change in replay:

1. Note the constant you want to change (e.g. `KF_R_MAG = 0.05` instead of `0.1`)
2. Edit `sunshine_core/include/sunshine_core.h`
3. Rebuild the app: `cd sunshine_app && pnpm tauri dev`
4. Reload the same `.sun` file in the Replay tab
5. Compare `replay.vars.est_theta` before and after

The replay always uses the currently compiled `sunshine_step()` — changing constants and recompiling is all that's needed.

---

## Reading the graph panel in replay

- **Solid lines:** Replayed series (1 kHz, full precision, recomputed)
- **Dotted/thin lines:** Real series (50 Hz, as stored in the file)
- **DShot:** Real = `inputs.dshot_left_q` (quantised 0–255, decoded). Replayed = `vars.dshot_cmd_left` (full 0–2047 float).
- **Zoom:** Ctrl+scroll
- **Pan:** Scroll
- **Time reference:** x-axis is `time_us` from `SunshineInput`, so it matches the robot's boot clock.

---

## Offline replay harness (`tools/replay/`) — CLI, no app required

For quick command-line analysis of a `.sun` file (CI, scripts, ad-hoc debugging)
without spinning up the Tauri app, use the standalone replay harness. It **links
the real `sunshine_core` sources** (no logic is reimplemented) and re-runs the
log's 1 kHz inputs through `sunshine_step()`, dumping every recomputed channel as
CSV at the full 1 kHz rate. This is the same code path the app's replay uses;
it's just a thin IO/glue layer so the parsing never has to be rewritten per task.

**Files:**
- `tools/replay/replay.c` — the harness (reads header-driven sizes + `num_inputs`,
  so it adapts to schema/format changes; unpacks fields from the packed on-disk
  offsets, never memcpy, so MSVC padding is irrelevant).
- `tools/replay/CMakeLists.txt` — cross-platform build (Windows MSVC / macOS /
  Linux). Also builds the `sunshine_core` unit tests on any toolchain.
- `tools/replay/msvc_compat.h` — force-included **only on MSVC** to strip GCC's
  `__attribute__((packed))` (native on gcc/clang).
- `tools/replay/analyze.py` — example analyses over the CSV (validate / gaps /
  precession). Reads only the CSV; reimplements no robot logic.
- `tools/replay/wheel_slip.py` — wheel overspeed and MELTY speed-cap report (see
  Scenario 5): measured-vs-no-slip eRPM ratio with its geometry regression guard,
  how often the cap binds and by how much, the overspeed distribution before and
  after, and an `--allow` sweep so `WHEEL_SLIP_ALLOW_MS` can be re-chosen against a
  real log without rebuilding firmware. Reads only the CSV; the **cap arithmetic is
  the one piece of robot logic it mirrors**, deliberately, because that is the thing
  under evaluation — `--vs-replay` diffs the mirror against the `dshot_l/r` the
  compiled `control.c` produced, and a non-zero median there means the two have
  drifted apart and the report is stale.

**Build (cross-platform — needs CMake + any C compiler):**
```bash
cd tools/replay
cmake -B build -S .          # configure (auto-detects MSVC / gcc / clang)
cmake --build build          # -> build/replay(.exe)  (+ test_* exes)
ctest --test-dir build       # run the sunshine_core unit tests
```
The `replay` binary lands in `build/` (or `build/Debug/` with the MSVC
multi-config generator). Examples below write to `/tmp`; on Windows use any
writable path.

**Run:**
```bash
# Continuous replay (seed state ONCE, free-run) — faithful 1 kHz trajectory:
build/replay LOG.sun > cont.csv
# Per-frame replay (re-seed from each frame's stored state) — for validation:
build/replay LOG.sun --reseed > reseed.csv
# Restrict to a time window (boot-clock microseconds):
build/replay LOG.sun --from-us 89628463 --to-us 90539463 > window.csv
```

CSV columns: `time_us, mode, ctrl_x, ctrl_y, ctrl_theta, ctrl_throttle,
input_dshot_l, input_dshot_r, input_dshot_l_q, input_dshot_r_q, kf_theta,
kf_omega, omega_accel, mag_angle, est_theta, est_omega, mag_x_filt, mag_y_filt,
heading_deg, led_on, mag_valid, accel_sat, dshot_l, dshot_r,
erpm_left, erpm_right, mag_x, mag_y, accel_x, accel_y, theta_offset,
stored_kf_theta, stored_kf_omega,
stored_theta_offset,` and (frame-end rows only)
`stored_est_theta, stored_mag_angle, stored_led_on`.
`input_dshot_l/r` are the robot-logged previous-tick DShot commands decoded from
the quantized `SunshineInput.dshot_*_q` fields; `dshot_l/r` are recomputed by the
current `sunshine_step()` for the current tick.
`stored_kf_theta/omega/theta_offset` are the real on-robot state snapshots from
the log. For VER 3 they appear at the frame-start row and midpoint row only; other
rows are blank because the log carries state at 100 Hz, not 1 kHz.
The `stored_*` columns are the **real on-robot** values from the file — pair them
with `--reseed` to validate replay reproduces the robot bit-for-bit.

**`--reseed` vs continuous:** `--reseed` seeds state from each frame's logged
"state at start" and should reproduce the stored vars *exactly* (replay
determinism check). Continuous free-runs from the first frame; to keep that
faithful when the log has a hole in the 1 kHz inputs, the harness **dead-reckons
the filter across detected timestamp gaps**. Use `analyze.py gaps` to see the rate.

**A timestamp gap has TWO possible causes — check `frame_id` to tell them apart:**
- **Dropped telemetry** — `frame_id` jumps by >1 across the gap. The robot ran
  1 kHz fine; the ESP-NOW link lost whole frames. (Reliable unicast makes this rare.)
- **Robot nav-loop STALL** — `frame_id` is *contiguous* across the gap, but the time
  between the last input of one frame and the first of the next is >1 ms. The robot
  itself stopped sampling. A known cause: `Serial.printf` (USB-CDC) blocking the
  1 kHz loop when no host drains the TX FIFO — fixed with `Serial.setTxTimeoutMs(0)`
  + `if (Serial)` guards (main.cpp / nav_control.cpp). A stall means the *robot's*
  control/heading froze for that long, not just a plotting hole — investigate it.

**Example analyses:**
```bash
python ../analyze.py validate   reseed.csv  # replay == real? (~0 deg)   [path: tools/replay/analyze.py]
python ../analyze.py gaps        cont.csv    # dropped-input check
python ../analyze.py precession  cont.csv    # LED drift vs raw-mag truth
python ../wheel_slip.py          cont.csv    # wheel overspeed + speed-cap report
python ../wheel_slip.py          cont.csv --allow 0.5,0.75,1.0,1.5,2.0 --vs-replay
```

The `precession` check is a useful pattern: it derives **ground-truth spin rate
straight from the raw magnetometer** (the field vector rotates once per
revolution about its hard-iron centre), independent of the filter, and compares
it to the LED heading-reference rate. Any difference is how fast the LED dot
precesses. The same raw-mag trick gives a filter-independent reference for
`est_omega` and `omega_from_accel` accuracy.

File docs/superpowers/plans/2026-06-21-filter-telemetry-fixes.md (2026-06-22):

# Sunshine Filter + Telemetry Fixes Implementation Plan

> **For agentic workers:** Steps use checkbox (`- [ ]`) syntax for tracking. Inline execution (no subagents) per user request.

**Goal:** Fix the MELTY heading false-lock (sim), stop the 1 kHz telemetry input drops (brain), and make the offline/app replay robust to any residual drops — so simulated and real data behave correctly and `real` matches `replay`.

**Architecture:** Three independent fixes. (1) `mag_heading.c` centres its tracking band-pass on the **loop-independent** accel rate instead of the fed-back `kf_omega`, breaking the parametric feedback that false-locks at half the true spin rate. (2) The brain's telemetry SPSC ring is enlarged (and drops are counted + printed over USB) so transient Core-0/WiFi preemption no longer silently discards 1 kHz inputs. (3) The host replay free-run dead-reckons the heading across input-timestamp gaps so lossy logs replay faithfully.

**Tech Stack:** C (sunshine_core, verified via the CMake replay harness + ctest), C++/Arduino-ESP32 (sunshine_brain, PlatformIO), Rust (sunshine_app Tauri backend, cargo test).

## Global Constraints

- **Schema is APPEND-ONLY and unchanged here.** `sizeof(SunshineState)==44`, `sizeof(SunshineInput)==29`, `sizeof(SunshineVars)==56`, `SUNSHINE_SCHEMA_VERSION==3`. None of these fixes add/remove/reorder struct fields — verify the FFI `const _` asserts and `tools/replay` still parse VER 3 logs after.
- **No git operations this session** (user instruction). Do not branch/commit; leave changes in the working tree.
- **`omega_from_accel` and `accel_saturated` are set on `vars` BEFORE `mag_heading_step` is called** (`brain.c:21,35` then `:57`) — Task 1 relies on this ordering; do not reorder `brain.c`.
- Build core/replay with the VS-bundled CMake: `"/c/Program Files/Microsoft Visual Studio/18/Community/Common7/IDE/CommonExtensions/Microsoft/CMake/CMake/bin/cmake.exe"`.

---

### Task 1: Break the mag-heading feedback false-lock (sim "bad results")

**Root cause (proven from `Simulation.sun`):** `mag_heading.c:42` sets the band-pass centre `fc = kf_omega/2π`, but `kf_omega` is driven by the heading that band-pass produces (`kalman_update_theta` cross-term + accel down-weighting). The per-tick coefficient retuning from this fed-back, oscillating `kf_omega` parametrically false-locks the recovered heading at **half** the true spin rate (true 201.7 rad/s → `kf_omega` 105, `mag_angle` rate 108.6). A *constant* `fc` recovers the true rate; centring on the **loop-independent** `omega_from_accel` recovers it in every tested window (200.9 / 114.2 / 362.0 vs true 201.7 / 115.1 / 363.7). This is the curvy-(not-straight)-sawtooth and `kf_omega`≠`omega_from_accel` the user saw.

**Files:**
- Modify: `sunshine_core/src/mag_heading.c:35-69` (fc source)
- Modify: `sunshine_core/include/sunshine_core.h:56-78` (band-pass comment block)
- Modify: `sunshine_core/src/brain.c:42-44` (comment only — note fc is now accel-driven)
- Test: `sunshine_core/test/test_mag_heading.c`
- Docs: `docs/DEBUGGING.md` (Scenario 1 note), `docs/FILTER_MATH.md` (Step 2 heading section)

**Interfaces:**
- Consumes: `SunshineVars.omega_from_accel` (f32, rad/s, 0 during saturation/zero), `SunshineVars.accel_saturated` (u8) — both already populated by `brain.c` before `mag_heading_step`.
- Produces: no signature change. `mag_heading_step(const SunshineInput*, SunshineState*, SunshineVars*)` unchanged.

- [ ] **Step 1: Write the failing test** — append to `test_mag_heading.c` before `TEST_RESULTS();`, and fix the existing spin test so it no longer relies on `kf_omega` for centring.

Replace the existing spin-test setup (lines 28-31) with:
```c
    sunshine_state_init(&s);
    memset(&in, 0, sizeof(in));
    memset(&v,  0, sizeof(v));
    float A = 22.0f, f = 20.0f;     /* µT, Hz */
    /* Fix: the band-pass centres on the LOOP-INDEPENDENT accel rate, NOT kf_omega.
       Set kf_omega deliberately WRONG (0) to prove the heading no longer depends
       on it; supply the true rate via omega_from_accel as brain.c does. */
    s.kf_omega          = 0.0f;
    v.accel_saturated   = 0;
    v.omega_from_accel  = 2.0f * 3.14159265f * f;
```
And add `memset(&v, 0, sizeof(v));` immediately after `sunshine_state_init(&s);` in the DC-blocked section (line 16-17) so the first calls read a defined `omega_from_accel==0` (→ kf_omega fallback, fc clamps to 8 Hz; DC is still blocked by the band-pass zero).

Also append a dedicated regression test:
```c
    /* Regression: a badly-wrong kf_omega must NOT drag the recovered heading rate
       (the old kf_omega-fed band-pass false-locked at half the true rate). */
    sunshine_state_init(&s);
    memset(&in, 0, sizeof(in));
    memset(&v,  0, sizeof(v));
    float Af = 22.0f, ff = 30.0f;          /* true spin 30 Hz */
    v.accel_saturated  = 0;
    v.omega_from_accel = 2.0f*3.14159265f*ff;
    float prevf = 0.0f, sumf = 0.0f; int Mf = 0;
    for (int n = 0; n < 4000; n++) {
        s.kf_omega = (n & 1) ? 50.0f : 250.0f;   /* oscillate kf_omega wildly each tick */
        float ph = 2.0f*3.14159265f*ff*n/1000.0f;
        in.mag_x = (int16_t)(Af*cosf(ph)/MAG_SCALE_UT);
        in.mag_y = (int16_t)(Af*sinf(ph)/MAG_SCALE_UT);
        mag_heading_step(&in, &s, &v);
        if (n > 2000) { sumf += wrap_pi(v.mag_angle - prevf); Mf++; }
        prevf = v.mag_angle;
    }
    float ratef = sumf / (Mf * 0.001f);
    ASSERT_NEAR(fabsf(ratef), 2.0f*3.14159265f*ff, 6.0f,
                "heading tracks true spin despite a wildly oscillating kf_omega");
```

- [ ] **Step 2: Run the test to verify it fails** (current code centres on `kf_omega`)

```bash
cd tools/replay
CMAKE="/c/Program Files/Microsoft Visual Studio/18/Community/Common7/IDE/CommonExtensions/Microsoft/CMake/CMake/bin/cmake.exe"
"$CMAKE" --build build --config Debug --target test_mag_heading
./build/Debug/test_mag_heading.exe
```
Expected: FAIL on "heading tracks true spin despite a wildly oscillating kf_omega" (and the modified spin test), because fc currently follows `kf_omega`.

- [ ] **Step 3: Implement the fix** — in `mag_heading.c`, replace the fc computation (lines 39-43):

```c
    /* Band-pass centre = spin frequency. Use the LOOP-INDEPENDENT accelerometer
     * rate (omega_from_accel), NOT kf_omega: the heading this band-pass produces
     * feeds kf_omega, so centring on kf_omega closes a feedback loop whose per-tick
     * coefficient modulation parametrically FALSE-LOCKS the recovered heading at
     * half the true spin rate. omega_from_accel is measured straight from the
     * accelerometer (independent of the heading), so it breaks the loop. During
     * accel saturation it is 0 → fall back to kf_omega for those brief ticks (far
     * too short to develop a false lock). brain.c sets both fields before this. */
    float spin_omega = (!v->accel_saturated && v->omega_from_accel > 0.0f)
                       ? v->omega_from_accel : s->kf_omega;
    float fc = spin_omega * (0.5f / M_PI_F);
    if (fc < MAG_BP_MIN_FC_HZ) fc = MAG_BP_MIN_FC_HZ;
```

- [ ] **Step 4: Run the unit test to verify it passes**

```bash
cd tools/replay
"$CMAKE" --build build --config Debug --target test_mag_heading
./build/Debug/test_mag_heading.exe
```
Expected: all assertions PASS.

- [ ] **Step 5: Run the FULL core test suite (no regressions)**

```bash
cd tools/replay
"$CMAKE" --build build --config Debug
ctest --test-dir build -C Debug --output-on-failure
```
Expected: all tests pass (kalman, brain, control, utils, mag_heading).

- [ ] **Step 6: Validate against the real sim log via replay**

```bash
cd tools/replay
./build/Debug/replay.exe ../../sunshine_brain/logs/2026-06-22_02-24-00_Simulation.sun > dbg/sim_fixed.csv
".venv python" dbg/c.py   # reuse: prints kf_omega vs omega_accel + mag_angle rate in the 19-23s window
```
Expected: in the 39%-throttle window, `kf_omega` mean ≈ **200** rad/s (was 105) and `mag_angle` rotation rate ≈ **200** (was 108.6); `kf_theta` is a straight (constant-rate) sawtooth. Use `python ../analyze.py precession dbg/sim_fixed.csv` to confirm LED rate ≈ raw-mag truth.

- [ ] **Step 7: Update the documentation** — `sunshine_core.h:56-78`, `brain.c:42-44`, `docs/DEBUGGING.md` Scenario 1, and `docs/FILTER_MATH.md` to state the band-pass centres on `omega_from_accel` (loop-independent), with the kf_omega-saturation fallback; remove claims that "the estimate only picks the band centre, so it cannot drift" (it could, via the loop).

---

### Task 2: Stop the brain dropping 1 kHz telemetry inputs

**Root cause (proven from `grounddata.sun`):** frame_ids are perfectly contiguous (zero frame loss) yet ~13% of 1 kHz inputs are missing, in ~20 ms holes. The nav loop busy-waits a true 1 kHz and runs `sunshine_step` on every tick (the logged real state is continuous — verified: 3.0° residual assuming continuous vs 34.4° assuming frozen). The loss is the **64-deep SPSC telem ring overflowing**: `telemetry_task` (Core 0, prio 5) shares Core 0 with the WiFi task (prio ~23) doing 500 Hz control RX + 50 Hz telem TX; a >64 ms WiFi/Core-0 preemption fills the ring and `RingBuffer::push` drops the input (returns false). The 167→50 Hz migration enlarged each TX (671 B, longer airtime/Core-0 hog per send) without enlarging the 64-deep ring (was 10× margin at 6 inputs/frame, only 3.2× at 20), so per-stall drops grew. Drops are invisible because `vars.loop_overrun` is never telemetered and nothing counts them.

**Files:**
- Modify: `sunshine_brain/src/telemetry.cpp:22` (ring depth) and add a drop counter + accessor
- Modify: `sunshine_brain/src/telemetry.h` (declare `telemetry_dropped_count()`)
- Modify: `sunshine_brain/src/nav_control.cpp:141-145,162-166` (count drops, print over USB in the existing PROF block)

**Interfaces:**
- Produces: `uint32_t telemetry_dropped_count(void);` — cumulative count of inputs `telemetry_push` could not enqueue.
- Consumes: existing `bool telemetry_push(const SunshineInput*, const SunshineState*)` return value (already returned, currently only sets `vars.loop_overrun`).

**Migration audit result (record in commit message / notes, no code needed):** Searched brain + receiver + host for 6-input / 167 Hz / 250-byte assumptions. The host (`protocol.rs`, `pipeline.rs`, `logging.rs`) and receiver (`espnow_rx.cpp`, `usb_bridge.cpp`) are all derived from `INPUTS_PER_FRAME`/`ESPNOW_TELEM_SIZE` and scale correctly. The only size that did **not** scale with the migration is this brain ring depth. The receiver's 2-slot last-value `telem_buf` double buffer (`espnow_rx.cpp:19`) holds only the newest frame; it did not drop here (frame_ids contiguous, USB keeps up at 50 Hz) but a lost frame now costs 20 inputs vs 6 — noted as a latent risk, left unchanged (no evidence of loss, changing it risks new bugs).

- [ ] **Step 1: Enlarge the ring** — `telemetry.cpp:22`:

```cpp
// Sized for transient Core-0/WiFi preemption: at 1 kHz, 256 entries = 256 ms of
// slack (observed worst-case stalls were ~40 ms). 256×sizeof(TelemetryEntry≈73B)
// ≈ 18 KB SRAM (ESP32-S3 has 512 KB). Was 64 (only 64 ms) — too small once the
// 50 Hz / 20-input framing made each TX a longer Core-0 hog. Power of 2 required.
static RingBuffer<TelemetryEntry, 256> telem_ring;
```

- [ ] **Step 2: Add a drop counter + accessor** — `telemetry.cpp`: add near the other statics, and update `telemetry_push`:

```cpp
static std::atomic<uint32_t> dropped_inputs{0};

bool telemetry_push(const SunshineInput *in, const SunshineState *state) {
    TelemetryEntry e;
    e.input = *in;
    e.state = *state;
    bool ok = telem_ring.push(e);
    if (!ok) dropped_inputs.fetch_add(1, std::memory_order_relaxed);
    return ok;
}

uint32_t telemetry_dropped_count(void) {
    return dropped_inputs.load(std::memory_order_relaxed);
}
```
Add `#include <atomic>` if not present (ring_buffer.h already pulls it, but include explicitly).

- [ ] **Step 3: Declare the accessor** — `telemetry.h`: add `uint32_t telemetry_dropped_count(void);` next to `telemetry_push`.

- [ ] **Step 4: Surface drops over USB** — `nav_control.cpp`, inside the existing `if (++prof_n % 500 == 0)` PROF print (line ~162), append the drop count so a dev with USB sees it without any UI:

```cpp
                Serial.printf("PROF us: adxl=%u mag=%u batt=%u ctrl=%u step=%u dshot=%u rest=%u | total=%u max=%u | telem_drop=%u\n",
                              adxl_us, mag_us, batt_us, ctrl_us, step_us, dshot_us, rest_us, elapsed, mx_total,
                              telemetry_dropped_count());
```
(Include `telemetry.h` is already included in nav_control.cpp.)

- [ ] **Step 5: Compile-check the firmware** (no hardware needed — just confirm it builds)

```bash
cd sunshine_brain
# PlatformIO via penv (see memory: invoke pio through penv exe, never bare `pio`)
~/.platformio/penv/Scripts/pio.exe run -e <env>   # adjust env name from platformio.ini
```
Expected: compiles clean. If the penv path differs, locate it first (`ls ~/.platformio/penv/Scripts/`). If the toolchain is unavailable in this environment, record that the change is source-correct and defer the on-device build to the user.

- [ ] **Step 6: Verify RAM headroom** — confirm the build's `.bss`/`DRAM` usage report still fits (the ring adds ~14 KB over the old 64-entry ring). Note the static RAM figure from the build output.

---

### Task 3: Make host replay robust to dropped inputs (real vs replay for lossy logs)

**Root cause:** the host's REPLAYED free-run steps every surviving input as a fixed 1 ms (`brain_step` → `DT=0.001`) and **ignores `input.time_us` gaps entirely** (`pipeline.rs` `build_replay_cache`, `ingest_frame`, `get_graph_data_from_log_meta`). Across each dropped-input hole the robot advanced its heading by the real elapsed time but replay advances only 1 ms, so the REPLAYED heading falls behind — 93° mean error on `grounddata.sun` vs 13° when the gap is dead-reckoned. (The REAL series re-anchors per frame, so it stays correct; this only fixes the free-running REPLAYED series.) Even after Task 2 reduces drops, RF noise guarantees some, so replay should ride across them.

**Files:**
- Modify: `sunshine_core/src/brain.c` — expose nothing new; `kalman_predict` is already a non-static symbol (used by `tools/replay`).
- Modify: `sunshine_app/src-tauri/src/ffi.rs` (add `kalman_predict` extern + safe wrapper)
- Modify: `sunshine_app/src-tauri/src/pipeline.rs` (`step_point` gains a gap-aware variant; the three free-run loops track previous hw time and dead-reckon `rep_state`)
- Test: `sunshine_app/src-tauri/src/pipeline.rs` (`#[cfg(test)]`)

**Interfaces:**
- Consumes: `kalman_predict(s: *mut SunshineState, dt: f32)` from sunshine_core (declared `void kalman_predict(SunshineState*, float)` in `brain.c`/`kalman.c`).
- Produces: `pub fn kalman_predict_state(state: &mut SunshineState, dt: f32)` in `ffi.rs`; `step_point` signature unchanged (REAL still re-anchored by caller); rep_state dead-reckon handled inside the loops.

- [ ] **Step 1: Write the failing test** — append to `pipeline.rs` tests: feed two frames whose inputs jump 20 ms between them and assert the free-run `rep_state.kf_theta` advances by ≈ `kf_omega × gap`, not by 1 ms.

```rust
    #[test]
    fn replay_deadreckons_rep_state_across_input_gaps() {
        // Two frames; second frame's inputs start 20 ms after the first ends.
        // rep_state spins at a fixed omega; across the gap the replayed heading
        // must advance by omega*gap (dead-reckoned), not by a single 1 ms step.
        let mut p = Pipeline::new();
        let omega = 50.0f32;
        let mut s = SunshineState::default(); state_init(&mut s); s.kf_omega = omega;
        // frame A: inputs at 0,1,..,19 ms
        let mut a = [SunshineInput::default(); INPUTS_PER_FRAME];
        for (i, inp) in a.iter_mut().enumerate() { inp.time_us = (i as u32)*1000; inp.mode = 0; }
        let fa = TelemetryFrame { frame_id: 0, state: s, state_mid: s, inputs: a };
        // frame B: inputs at 40,41,..,59 ms  (20 ms hole after A's last input at 19 ms)
        let mut b = [SunshineInput::default(); INPUTS_PER_FRAME];
        for (i, inp) in b.iter_mut().enumerate() { inp.time_us = 40_000 + (i as u32)*1000; inp.mode = 0; }
        let fb = TelemetryFrame { frame_id: 1, state: s, state_mid: s, inputs: b };
        p.begin_sim();              // resets, seeds rep_state from first frame
        p.ingest_frame(&fa);
        p.ingest_frame(&fb);
        // rep.kf_theta at the first input of frame B vs the last input of frame A
        let last_a  = p.get_channel_snapshot(&["rep.kf_theta".into()], Some(19_000))[0].unwrap();
        let first_b = p.get_channel_snapshot(&["rep.kf_theta".into()], Some(40_000))[0].unwrap();
        let adv = (first_b - last_a).abs();
        // continuous robot would advance ~omega*21ms ≈ 1.05 rad across the hole+step;
        // the old fixed-1ms replay advances only ~omega*1ms ≈ 0.05 rad.
        assert!(adv > 0.5, "rep_state must dead-reckon the gap (got {adv} rad)");
    }
```

- [ ] **Step 2: Run it to verify it fails**

```bash
cd sunshine_app/src-tauri
cargo test replay_deadreckons_rep_state_across_input_gaps -- --nocapture
```
Expected: FAIL (`adv` ≈ 0.05, replay ignores the gap).

- [ ] **Step 3: Expose `kalman_predict` in `ffi.rs`** — add to the `extern "C"` block and a wrapper:

```rust
extern "C" {
    // ... existing ...
    fn kalman_predict(s: *mut SunshineState, dt: f32);
}

/// Dead-reckon the filter forward by `dt` seconds (predict only, no measurement).
/// Used to advance the free-running replay across dropped-input timestamp gaps.
pub fn kalman_predict_state(state: &mut SunshineState, dt: f32) {
    unsafe { kalman_predict(state as *mut _, dt) }
}
```

- [ ] **Step 4: Dead-reckon `rep_state` across gaps in the three free-run loops** — `pipeline.rs`. Add a helper and call it before each `brain_step` on `rep_state` in `ingest_frame` (`:90-94`), `get_graph_data_from_log_meta` (`:279-291`), and `build_replay_cache` (`:421-429`). Track the previous input hardware time per loop.

Helper (module-level in pipeline.rs):
```rust
/// If the input timeline jumped (a dropped-input hole the robot ran through but
/// telemetry didn't capture), advance the free-running rep filter across it so its
/// heading doesn't fall behind. The robot used a fixed 1 ms DT per real tick; we
/// approximate the missing ticks with one predict of (gap - 1 ms). >1.5 ms = a gap;
/// cap at 100 ms to ignore session restarts / clock resets.
fn deadreckon_gap(rep_state: &mut SunshineState, prev_hw_us: &mut Option<u32>, now_hw_us: u32) {
    if let Some(prev) = *prev_hw_us {
        let gap = now_hw_us.wrapping_sub(prev);
        if gap > 1500 && gap < 100_000 {
            kalman_predict_state(rep_state, (gap - 1000) as f32 / 1e6);
        }
    }
    *prev_hw_us = Some(now_hw_us);
}
```
In each loop, declare `let mut rep_prev_hw: Option<u32> = None;` alongside the existing `rep_seeded`, and immediately before the `brain_step(input, &mut rep_state)` (or inside `step_point` — see below) call `deadreckon_gap(&mut rep_state, &mut rep_prev_hw, input.time_us);`. For `ingest_frame`, store `rep_prev_hw` as a `Pipeline` field (reset in `begin_live`/`begin_sim` to `None`) since it persists across frames; for the two batch loops it is a local. Do NOT dead-reckon `real_state` (it is re-anchored every frame).

Concretely for `ingest_frame`: add field `rep_prev_hw: Option<u32>` to `Pipeline`, init `None` in `new`/`begin_live`/`begin_sim`, and in the input loop:
```rust
            let real_vars = brain_step(input, &mut self.real_state);
            deadreckon_gap(&mut self.rep_state, &mut self.rep_prev_hw, input.time_us);
            let rep_vars  = brain_step(input, &mut self.rep_state);
```
For `get_graph_data_from_log_meta` and `build_replay_cache`, add `let mut rep_prev_hw: Option<u32> = None;` next to `rep_seeded` and call `deadreckon_gap(&mut rep_state, &mut rep_prev_hw, input.time_us);` right before the `step_point(...)` call (and have `step_point` keep stepping both as today — the dead-reckon happens just before it on `rep_state`).

- [ ] **Step 5: Run the test to verify it passes**

```bash
cd sunshine_app/src-tauri
cargo test replay_deadreckons_rep_state_across_input_gaps -- --nocapture
```
Expected: PASS (`adv` ≈ 1.0 rad).

- [ ] **Step 6: Run the full backend test suite (no regressions)**

```bash
cd sunshine_app/src-tauri
cargo test
```
Expected: all pipeline/protocol tests pass.

- [ ] **Step 7: End-to-end check against the real log** (matches the harness's dead-reckon result)

Confirm via the already-built harness that dead-reckoning brings continuous replay to ~13° of the logged real state (vs 93° without): `tools/replay/build/Debug/replay.exe grounddata.sun` already dead-reckons; the app now matches that behaviour. Note the number in the verification summary.

---

## Verification Summary (run after all tasks)

- [ ] `ctest --test-dir tools/replay/build -C Debug` — all core tests green (incl. new mag-heading regression).
- [ ] Replay `Simulation.sun`: `kf_omega` tracks `omega_from_accel` (~200 in the 39% window), `kf_theta` straight sawtooth, `analyze.py precession` ≈ 0 drift.
- [ ] `cargo test` in `sunshine_app/src-tauri` — green incl. the new gap dead-reckon test.
- [ ] Firmware compiles (or source-correctness recorded if toolchain unavailable); note static RAM headroom.
- [ ] Schema asserts intact: `sizeof` State/Input/Vars unchanged; `tools/replay` still parses both logs.

## Self-Review Notes

- **Spec coverage:** Sim false-lock → Task 1. Brain input drops + migration audit → Task 2. Real-vs-replay (dropped-input cause) → Task 2 (root) + Task 3 (replay robustness). "Make errors obvious" → Task 2 Step 4 (USB drop counter; UI work skipped per user since the fix is brain-side).
- **No schema change** in any task → FFI asserts and VER-3 log parsing remain valid.
- **Type consistency:** `telemetry_dropped_count` (Task 2) and `kalman_predict_state`/`deadreckon_gap` (Task 3) names used consistently across their steps.

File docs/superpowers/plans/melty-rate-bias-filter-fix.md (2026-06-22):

# MELTY Heading Rate-Bias Filter Fix — Validation & Tuning Plan

> **For agentic workers:** REQUIRED SUB-SKILL: `superpowers:systematic-debugging` and `superpowers:executing-plans`. **Do NOT run git operations** (the human commits). The `.sun` log format and how to build/run the offline replay harness (`tools/replay/`) + `analyze.py` are in `docs/DEBUGGING.md` — read it first; this plan assumes it.

**The fix is already implemented and validated against the existing (imperfect) logs.** This plan is to **confirm and fine-tune it on a freshly captured clean log**, and to escalate to a second stage only if needed. It concerns ONLY the navigation filter / MELTY heading-LED precession — not telemetry format, app, etc.

> **What's implemented now (read this — supersedes the "approaches" framing below):**
> 1. **Open-loop magnetometer heading** (`sunshine_core/src/mag_heading.c`): each mag axis is high-passed (2nd-order Butterworth, `MAG_HP_*`, fc=0.5 Hz) to strip the body-fixed DC (hard-iron + average ESC current), then `mag_angle = atan2(-my_hp, mx_hp)`. This is **open-loop** — independent of the estimate — so it cannot drift (replaced the old closed-loop synchronous demodulator). Full math in FILTER_MATH.md §Step 2.
> 2. **Trust the (now clean, absolute) mag**: `KF_R_MAG` lowered 0.1 → **0.01**.
> 3. **Accel rate down-weighting once locked**: `KF_R_ACCEL_LOCKED = 80` used when `mag_valid`, `KF_R_ACCEL = 0.5` during spin-up (`brain.c`).
>
> **Replay result on the old logs:** the high-passed field is a steady ~22 µT every window (clean), and precession on the longest window is ~+0.3 rev/s (was ~+2). Shorter windows scatter ±0.5 rev/s — but those are 0.3–0.9 s transient-contaminated chunks from gappy logs, so the **clean-log confirmation below is what matters**.
>
> **Remaining task:** capture a clean log (§3), confirm precession < 0.5 rad/s across all speeds, and fine-tune `KF_R_MAG` / `KF_R_ACCEL_LOCKED` (§ tuning). If a speed-dependent residual remains, escalate to the additive ω-bias state (§4). Schema is now v3, `SunshineState` = 44 bytes.

**Goal:** In MELTY the heading LED (lit within ±3° of zero heading) should look *stationary*. It used to precess ~2 rev/s while the robot spins ~40 rev/s. The implemented fix cut that to ~0.5 rev/s in replay; confirm it's visually stationary on hardware and fine-tune.

---

## 1. Minimum robot context

1 lb melty-brain combat robot: the whole body spins (~2000–2500 RPM) and wheel speeds modulate per-revolution to translate. An ESP32-S3 runs a 1 kHz nav+control loop. The navigation Kalman filter (`sunshine_core/`, shared C also run on the host for replay) estimates heading `θ` and spin rate `ω`:
- **Accelerometer (ADXL375, ~11 mm from spin centre):** centripetal accel → `ω_accel = sqrt(|a|/r)`. High-bandwidth, always available, but **biased ~5–8% high** (effective radius ≠ assumed 11 mm + tangential accel from drive ripple; the bias also *varies with speed*).
- **Magnetometer (LIS3MDL):** Earth field rotates once per body revolution; a synchronous demodulator (`derot_filter.c`) derotates by estimated `θ` → `mag_angle`, an **absolute** heading reference, valid only while spinning (`ω > SUNSHINE_MAG_MIN_OMEGA = 4π rad/s ≈ 120 RPM`).
- The Kalman fuses accel→`ω`, mag→absolute `θ`. LED lights when `wrap(kf_theta + theta_offset)` is within ±3°.

Files: `sunshine_core/src/{kalman,brain,derot_filter}.c`, `include/sunshine_core.h` (tuning `#define`s, `#ifndef`-guarded → overridable with `-D`). Tuning constants: `KF_Q_THETA`, `KF_Q_OMEGA`, `KF_R_ACCEL`, **`KF_R_ACCEL_LOCKED`** (new), `KF_R_MAG`.

---

## 2. Root cause (confirmed) and the implemented fix

**Root cause:** `ω_accel` is biased high. `kf_omega` locks onto that biased value during spin-up (when `P_ωω` is large and the accel update dominates); then `P_ωω` collapses and neither sensor strongly re-corrects `ω`. The magnetometer corrects the *angle* well (`derot |I,Q|` ≈ 20 µT of ~22) but a persistent ~10 rad/s rate error drifts faster than the angle correction can null → the LED precesses at roughly the residual bias. Confirmed against the raw magnetometer (filter-independent ground truth: the field vector rotates once per rev about its hard-iron centre).

**The fix (implemented):** keep the accelerometer as the high-bandwidth primary, but **down-weight it once the magnetometer is locked** so the absolute mag governs the steady-state rate (a type-2 PLL nulls the frequency error). Concretely, in `sunshine_core/`:
- `kalman_update_omega(s, omega_meas, r_accel)` now takes the measurement variance as an argument.
- `brain.c` computes `mag_valid` *before* the accel update and passes `KF_R_ACCEL_LOCKED` (weak) when locked, `KF_R_ACCEL` (strong) during spin-up so `ω` can still climb to the mag-valid threshold.
- Constants: `KF_R_ACCEL = 0.5` (spin-up, unchanged), **`KF_R_ACCEL_LOCKED = 80.0`** (locked), `KF_Q_OMEGA` raised `1e-3 → 1e-2` (so `ω` stays correctable by the mag — alone it does nothing; it only helps once the accel is down-weighted).
- Unit tests in `test_kalman.c` lock both behaviours (locked → mag pulls `ω` to truth despite biased accel; trusted → `ω` follows the biased accel for spin-up).

### Validation on the EXISTING logs (already done)
Using `tools/replay/replay.exe <log> | analyze.py precession` (the harness dead-reckons across logged input gaps so the filter is at steady-state by each gap-free window; precession = replayed heading rate − raw-mag true Ω):

| window | baseline precession | with fix |
|---|---|---|
| 0.91 s @ 2388 RPM (longest, most reliable) | +12.4 rad/s (+1.97 rev/s) | **+2.8 rad/s (+0.44 rev/s)** |
| other steady windows | +5…+6 rad/s | −0.5…−1 rev/s |
| 0.34 s @ 2259 RPM (transient) | +27 rad/s | +20 rad/s ⚠ |

Spin-up still reaches lock (`mag_valid` 99%+, `ω` 11→271 rad/s, no NaN/divergence). C unit tests 5/5 pass. So the fix is real and substantial (~4× reduction), and stable (no demod-collapse feedback like the abandoned approach in §5).

---

## 3. Confirm & fine-tune on a clean log (the main task)

The existing logs drop ~5% of inputs and have **no gap-free window > ~0.9 s**, so the per-window scatter above is partly measurement noise and partly the *speed-varying* bias. A clean 50 Hz log (the telemetry was moved to ESP-NOW v2 to stop the drops) will let you confirm and refine.

- [ ] **Flash both boards** (build clean; invoke pio via the penv exe, NOT bare `pio`):
  - `~/.platformio/penv/Scripts/pio.exe run -d sunshine_brain -e production -t upload`
  - `~/.platformio/penv/Scripts/pio.exe run -d sunshine_receiver -t upload`
- [ ] **Capture** a MELTY log (host app logs to `~/Documents/sunshine_logs/*.sun`): spin-up + **≥30 s steady at 2–3 throttle levels** (~1500/2000/2500 RPM) + a spin-down. Label it.
- [ ] **Confirm it's clean:** build the harness (DEBUGGING.md → "Offline replay harness"), then `python tools/replay/analyze.py gaps <log>.csv` → dropped inputs must be ≈ 0.
- [ ] **Measure precession:** `python tools/replay/analyze.py precession <log>.csv`. **Pass: |precession| < 0.5 rad/s across ALL steady windows and all speeds**, derot lock > 20 µT, no flagged outliers (other than genuine throttle transitions).
- [ ] **On the robot:** spin up in MELTY and look at the LED — it should be a near-stationary dot. (Heading flash is full brightness; idle is the dim breathe.)

### Fine-tuning `KF_R_ACCEL_LOCKED` (the main knob)
Override without editing source via the harness build flags (constant is `#ifndef`-guarded), e.g. configure a build with `-DCMAKE_C_FLAGS="-DKF_R_ACCEL_LOCKED=120.0f -DKF_Q_OMEGA=1e-2f"` and re-run `analyze.py precession`. Behaviour observed on existing data:
- **Higher `KF_R_ACCEL_LOCKED`** (weaker accel) → less precession, until it **overshoots negative** (~200 over-corrected to −1.8 rev/s and degraded the lock). The sweet spot was ~75–100; the longest window nulled at ~100.
- **Lower** → precession returns toward the biased-accel value.
- `KF_Q_OMEGA` alone does nothing — only matters paired with a down-weighted accel.
- Pick the value that minimizes |precession| across **all** speeds in the clean log (the optimum may differ from 80 once the data is clean). Keep `KF_R_ACCEL` (spin-up) at 0.5 — verify spin-up still reaches `mag_valid` after any change.
- Re-run `ctest --test-dir tools/replay/build` after every change.

---

## 4. Escalation (only if §3 can't hit < 0.5 rad/s across speeds)

If a single `KF_R_ACCEL_LOCKED` leaves a speed-dependent residual (because the accel bias varies with speed), add an **online ω-bias state** to absorb the slow systematic component:
- Append `kf_omega_bias` (+ its covariance terms) to `SunshineState` — **append-only**, so bump `SUNSHINE_SCHEMA_VERSION`, update the Rust mirror `sunshine_app/src-tauri/src/ffi.rs` (struct + `size_of` assert) and the harness `tools/replay/replay.c` (unpacks state by byte offset).
- Use an **additive** bias (linear: accel measures `ω + b`, `H=[0,1,1]`), NOT a scale factor (see §5).
- **Freeze `b` whenever `!mag_valid`** (zero its covariance coupling that tick) and **bound** it with a **small** `Q` so it adapts over seconds. The mag's angle innovation makes `b` observable via the cross-covariance.
- Validate exactly as §3, additionally confirming `b` converges and stays bounded (dump it from the replay CSV) and that it's stable across spin-up/down.

## 5. What NOT to do (already tried and failed)
A 3-state EKF with an accelerometer **scale factor** `s` (`ω_accel = ω·(1+s)`) passed an idealized unit test but **railed/diverged on real data**: positive feedback (scale↑ → corrected ω↓ → demod reference slips off the field → derot collapses → `mag_angle` garbage → scale↑) drove `s` to its clamp. The gaps + lack of a long convergence window made it untunable. The implemented §2 fix (down-weighting, no learned multiplicative state in the demod loop) avoids that feedback entirely. If you add a bias state (§4), keep it additive, gated to mag-valid, and slow — and watch for the same demod-slip instability.

## 6. Done when
The MELTY heading LED is visually stationary on hardware, and in replay on a clean log |precession| < 0.5 rad/s across all speeds with derot > 20 µT, no spin-up regression, and `ctest` green.

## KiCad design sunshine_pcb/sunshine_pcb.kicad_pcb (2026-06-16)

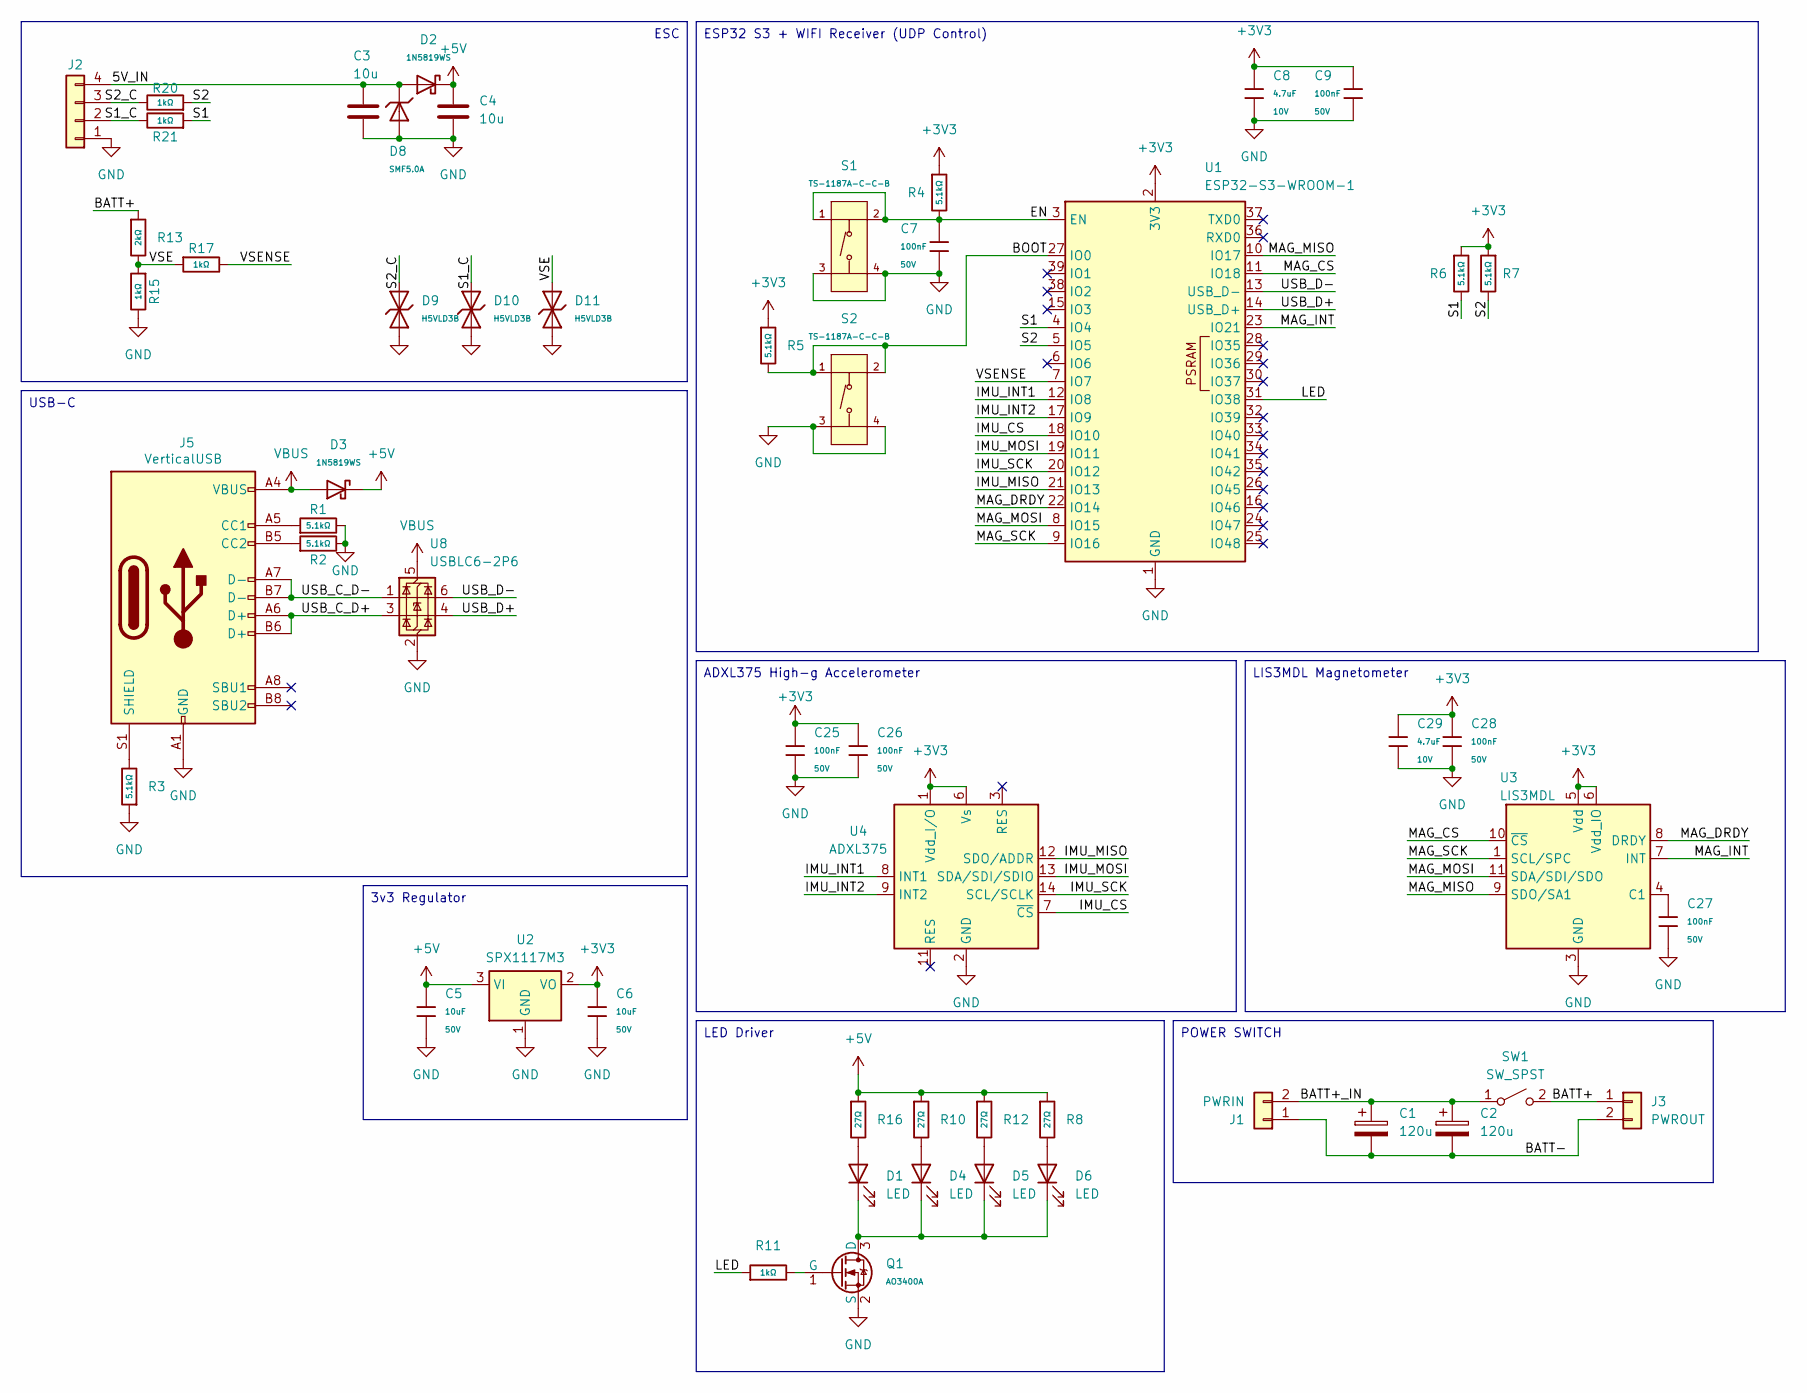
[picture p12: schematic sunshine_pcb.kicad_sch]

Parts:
C1, C2: 120u; CP_Radial_D6.3mm_P2.50mm
C3, C4: 10u; C_1210_3225Metric; LCSC C437431
C5, C6: 10uF; C_0805; Voltage Rated 50V; Tolerance ±10%; Part GRM21BR61H106KE43L; LCSC C440198
C7, C9, C25, C26, C27, C28: 100nF; C_0402; Voltage Rated 50V; Tolerance ±10%; Part CL05B104KB54PNC; LCSC C307331
C8, C29: 4.7uF; C_0402; Voltage Rated 10V; Tolerance ±20%; Part CL05A475MP5NRNC; LCSC C23733
D1, D4, D5, D6: LED; LED_PLCC_2835; LCSC C2843876
D2, D3: 1N5819WS; D_SOD-323; Forward Voltage (Vf@If) 600mV@1A; Reverse Voltage (Vr) 40V; Part 1N5819WS; LCSC C191023
D8: SMF5.0A; D_SOD-123FL; Part SMF5.0A; LCSC C19077497
D9, D10, D11: H5VLD3B; D_SOD-323; Part H5VLD3B; LCSC C20615805
J1: PWRIN; AMASS_XT30PW-M_1x02_P2.50mm_Horizontal
J2: Conn_01x04; SolderConnector4P; LCSC C122413
J3: PWROUT; SolderWire-1.5sqmm_1x02_P6mm_D1.7mm_OD3mm
J5: VerticalUSB; CONN_GT-USB-7055A_GSW
Q1: AO3400A; Q_SOT-23; Part AO3400A; LCSC C20917
R1, R2, R3, R4, R5, R6, R7: 5.1kΩ; R_0402; Overload Voltage (Max) 50V; Tolerance ±1%; Part 0402WGF5101TCE; LCSC C25905
R8, R10, R12, R16: 27Ω; R_0805; Overload Voltage (Max) 150V; Tolerance ±1%; Part 0805W8F270JT5E; LCSC C17594
R11, R15, R17, R20, R21: 1kΩ; R_0402; Overload Voltage (Max) 50V; Tolerance ±1%; Part 0402WGF1001TCE; LCSC C11702
R13: 2kΩ; R_0402; Overload Voltage (Max) 50V; Tolerance ±1%; Part 0402WGF2001TCE; LCSC C4109
S1, S2: TS-1187A-C-C-B; SW-SMD_4P-L5.1-W5.1-P3.70-LS6.5-TL-2; Voltage Rating (Dc) 12V; Part TS-1187A-B-A-B; LCSC C318889
SW1: SW_SPST; screw_switch
U1: ESP32-S3-WROOM-1; LCSC C2913202
U2: SPX1117M3; SOT-223-3_TabPin2; LCSC C6862
U3: LIS3MDL; LGA-12_2x2mm_P0.5mm; LCSC C478483
U4: ADXL375; LGA-14_3x5mm_P0.8mm_LayoutBorder1x6y; LCSC C481898
U8: USBLC6-2P6; SOT-666; LCSC C15999

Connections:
+3V3: C6.1, C8.1, C9.1, C25.1, C26.1, C28.1, C29.1, R4.1, R5.1, R6.1, R7.1, U1.2 (3V3), U2.2 (VO), U3.5 (Vdd), U3.6 (Vdd_IO), U4.1 (Vdd_I/O), U4.6 (Vs)
+5V: C4.1, C5.1, D2.1, D3.1, R8.1, R10.1, R12.1, R16.1, U2.3 (VI)
/5V_IN: C3.1, D2.2, D8.1, J2.4
/BATT+: J3.1, R13.1, SW1.2 (B)
/BATT+_IN: C1.1, C2.1, J1.2, SW1.1 (A)
/BATT-: C1.2, C2.2, J1.1, J3.2
/BOOT: R5.2, S2.1 (A), S2.2 (B), U1.27 (IO0)
/EN: C7.1, R4.2, S1.1 (A), S1.2 (B), U1.3 (EN)
/IMU_CS: U1.18 (IO10), U4.7 (~CS)
/IMU_INT1: U1.12 (IO8), U4.8 (INT1)
/IMU_INT2: U1.17 (IO9), U4.9 (INT2)
/IMU_MISO: U1.21 (IO13), U4.12 (SDO/ADDR)
/IMU_MOSI: U1.19 (IO11), U4.13 (SDA/SDI/SDIO)
/IMU_SCK: U1.20 (IO12), U4.14 (SCL/SCLK)
/LED: R11.1, U1.31 (IO38)
/MAG_CS: U1.11 (IO18), U3.10 (~CS)
/MAG_DRDY: U1.22 (IO14), U3.8 (DRDY)
/MAG_INT: U1.23 (IO21), U3.7 (INT)
/MAG_MISO: U1.10 (IO17), U3.9 (SDO/SA1)
/MAG_MOSI: U1.8 (IO15), U3.11 (SDA/SDI/SDO)
/MAG_SCK: U1.9 (IO16), U3.1 (SCL/SPC)
/S1: R6.2, R21.1, U1.4 (IO4)
/S1_C: D10.2, J2.2, R21.2
/S2: R7.2, R20.1, U1.5 (IO5)
/S2_C: D9.2, J2.3, R20.2
/USB_C_D+: J5.A6 (D+), J5.B6 (D+), U8.3 (I/O2)
/USB_C_D-: J5.A7 (D-), J5.B7 (D-), U8.1 (I/O1)
/USB_D+: U1.14 (USB_D+), U8.4 (I/O2)
/USB_D-: U1.13 (USB_D-), U8.6 (I/O1)
/VSE: D11.2, R13.2, R15.1, R17.1
/VSENSE: R17.2, U1.7 (IO7)
GND: C3.2, C4.2, C5.2, C6.2, C7.2, C8.2, C9.2, C25.2, C26.2, C27.2, C28.2, C29.2, D8.2, D9.1, D10.1, D11.1, J2.1, J5.A1 (GND), J5.A12 (GND), J5.B1 (GND), J5.B12 (GND), Q1.2 (S), R1.2, R2.2, R3.1, R15.2, S1.3 (C), S1.4 (D), S2.3 (C), S2.4 (D), U1.1 (GND), U1.40 (GND), U1.41 (GND), U2.1 (GND), U3.2 (GND), U3.3 (GND), U3.12 (GND), U4.2 (GND), U4.4 (GND), U4.5 (GND), U8.2 (GND)
unnamed: D1.2 (A), R16.2
unnamed: D1.1 (K), D4.1 (K), D5.1 (K), D6.1 (K), Q1.3 (D)
unnamed: D4.2 (A), R10.2
unnamed: D5.2 (A), R12.2
unnamed: D6.2 (A), R8.2
unnamed: J5.A5 (CC1), R1.1
unnamed: J5.B5 (CC2), R2.1
unnamed: J5.S1 (SHIELD), R3.2
unnamed: Q1.1 (G), R11.2
unnamed: C27.1, U3.4 (C1)
VBUS: D3.2, J5.A4 (VBUS), J5.A9 (VBUS), J5.B4 (VBUS), J5.B9 (VBUS), U8.5 (VBUS)

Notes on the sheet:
ADXL375 High-g Accelerometer
ESC
LIS3MDL Magnetometer
LED Driver
3v3 Regulator
POWER SWITCH
USB-C
ESP32 S3 + WIFI Receiver (UDP Control)

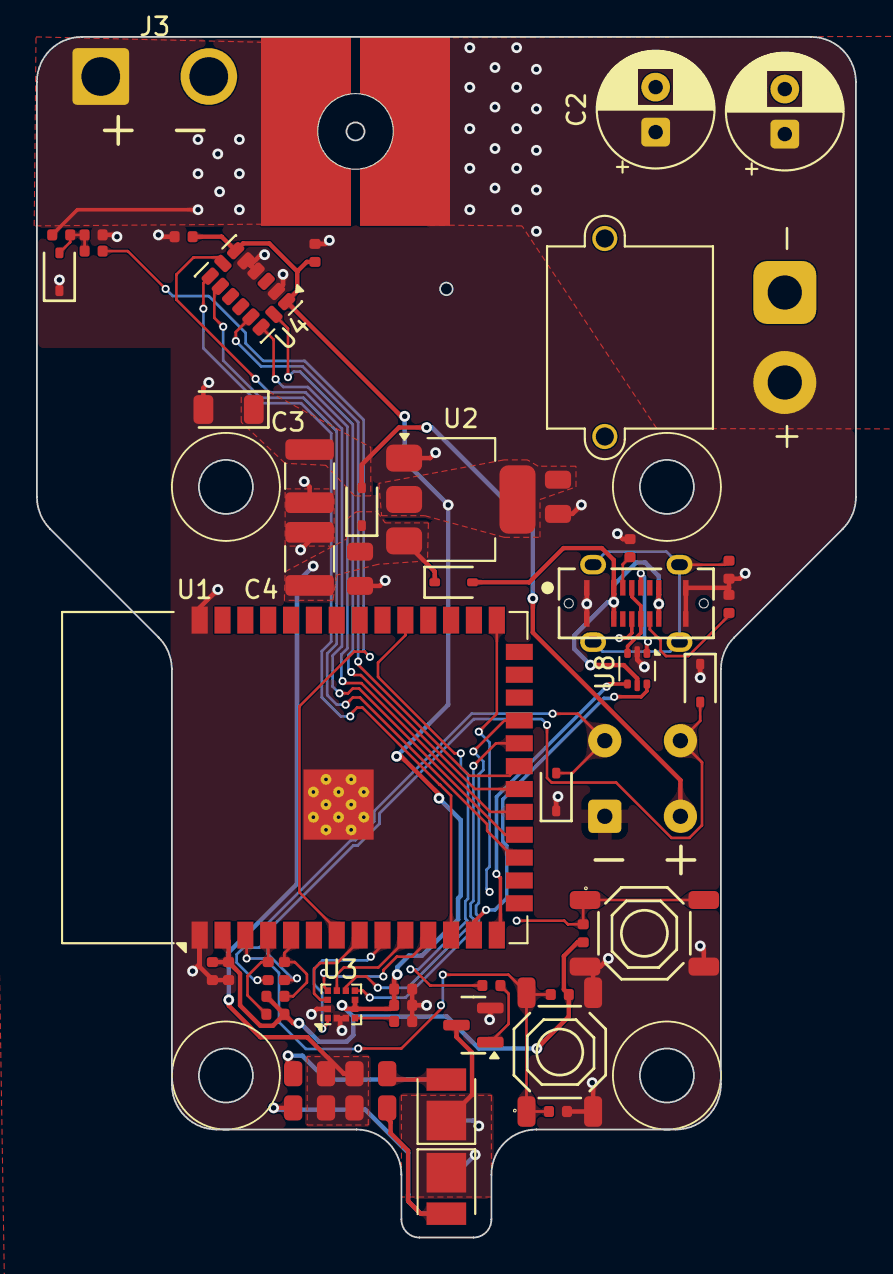
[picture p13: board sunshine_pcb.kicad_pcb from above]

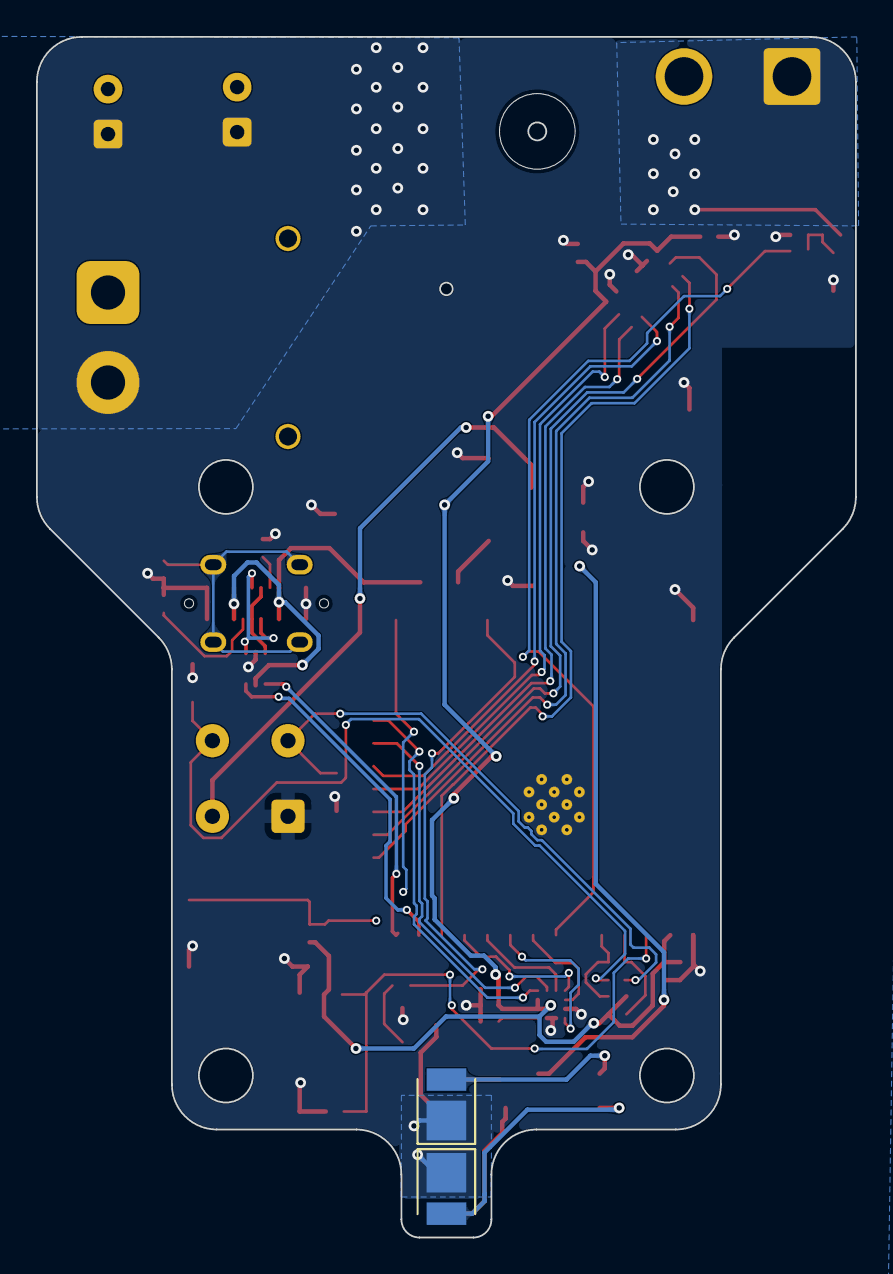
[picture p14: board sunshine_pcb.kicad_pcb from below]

Board: 4 copper layers, 45.5 x 66.7 mm, 54 parts (2 on the bottom side), 43 nets.

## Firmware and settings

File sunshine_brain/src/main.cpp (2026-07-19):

// src/main.cpp
// Sunshine Brain — main entry point
// Initialises all subsystems in order, handles init failures with LED patterns.
// Core 0: telemetry_task (FreeRTOS, priority 5)
// Core 1: nav_control_task (FreeRTOS, priority 10, pinned)

#include "bringup.h"
#include "config.h"
#include "sensors/adxl375.h"
#include "sensors/lis3mdl.h"
#include "dshot.h"
#include "telemetry.h"
#include "nav_control.h"
#include <Arduino.h>
#include <freertos/FreeRTOS.h>
#include <freertos/task.h>

// ── Error LED patterns ────────────────────────────────────────────────────────
// N fast blinks (50ms on/off) → 1s off → repeat
// Also prints error continuously to USB serial.
static void error_halt(int blink_count, const char *msg) {
    Serial.printf("FATAL INIT ERROR: %s (blink=%d)\n", msg, blink_count);
    while (true) {
        for (int i = 0; i < blink_count; i++) {
            analogWrite(PIN_LED, LED_DUTY_IDLE); delay(50);
            analogWrite(PIN_LED, 0);             delay(50);
        }
        delay(1000);
        Serial.printf("ERROR: %s\n", msg);  // repeat for late USB attach
    }
}

void setup() {
    Serial.begin(921600);
    // CRITICAL: make USB-CDC writes NON-BLOCKING. With ARDUINO_USB_CDC_ON_BOOT the
    // Serial TX FIFO fills whenever no host is draining it (i.e. whenever the robot
    // is spinning untethered), and the default timeout makes Serial.printf BLOCK on
    // a full FIFO — which stalled the 1 kHz nav loop for ~60 ms (seen as a timestamp
    // gap in the log). 0 → drop bytes instead of blocking; debug output is never
    // worth stalling the safety-critical control loop. (Also guard hot-path prints
    // with `if (Serial)` in nav_control.cpp.)
    Serial.setTxTimeoutMs(0);
    pinMode(PIN_LED, OUTPUT);
    analogReadResolution(12);

    // ── Level 1+ : init sensors ───────────────────────────────────────────────
    if (!adxl375_init()) error_halt(1, "ADXL375 init failed");
    if (!lis3mdl_init())  error_halt(2, "LIS3MDL init failed");

#if BRINGUP_LEVEL == 1
    // Bringup 1: CSV output only
    Serial.println("BRINGUP 1: accel_x,accel_y,accel_z,mag_x,mag_y,mag_z,batt_v");
    return;  // don't start tasks
#endif

    // ── Level 2+ : init DShot ─────────────────────────────────────────────────
#if FEATURE_DSHOT
    if (!dshot_init()) error_halt(3, dshot_last_error());
#endif

#if BRINGUP_LEVEL == 2
    // Bringup 2: interactive DShot test only
    Serial.println("BRINGUP 2: DShot test. l <val>, r <val>, s, t, d  (wait ~0.5s for ESC to arm)");
    return;
#endif

    // ── Level 3+ : init telemetry and start tasks ─────────────────────────────
#if FEATURE_TELEMETRY
    telemetry_init();
    // Stage A (assemble/drain) and Stage B (send) decoupled via an internal FIFO —
    // a slow send can't stall the 1 kHz input-ring drain. Both on Core 0.
    if (xTaskCreatePinnedToCore(telemetry_task, "telem_asm", 8192, nullptr, 5, nullptr, 0) != pdPASS) {
        error_halt(4, "telemetry assemble task create failed");
    }
    if (xTaskCreatePinnedToCore(telemetry_send_task, "telem_tx", 8192, nullptr, 5, nullptr, 0) != pdPASS) {
        error_halt(4, "telemetry send task create failed");
    }
#endif

    nav_control_init();
    if (xTaskCreatePinnedToCore(nav_control_task, "nav_ctrl", 8192, nullptr, 10, nullptr, 1) != pdPASS) {
        error_halt(5, "nav_ctrl task create failed");
    }

    Serial.printf("Brain ready (bringup=%d)\n", BRINGUP_LEVEL);
}

void loop() {
    // Bringup 1 and 2 use loop(); production uses FreeRTOS tasks.
#if BRINGUP_LEVEL == 1
    Adxl375Sample a = adxl375_read();
    MagSample     m = lis3mdl_read();
    float         v = batt_read_v();
    Serial.printf("%d,%d,%d,%d,%d,%d,%.3f\n",
                  a.x, a.y, a.z, m.x, m.y, m.z, v);
    delay(10);

#elif BRINGUP_LEVEL == 2
    static char     cmd[32];
    static int      ci = 0;
    static uint16_t cmd_left  = 0;
    static uint16_t cmd_right = 0;
    while (Serial.available()) {
        char c = Serial.read();
        if (c == '\n' || c == '\r') {
            cmd[ci] = '\0'; ci = 0;
            int v;
            if (cmd[0] == 'l') {
                v = atoi(cmd + 2);
                v = v < 0 ? 0 : v > 2047 ? 2047 : v;
                cmd_left = (uint16_t)v;
                Serial.printf("L→%d\n", v);
            } else if (cmd[0] == 'r') {
                v = atoi(cmd + 2);
                v = v < 0 ? 0 : v > 2047 ? 2047 : v;
                cmd_right = (uint16_t)v;
                Serial.printf("R→%d\n", v);
            } else if (cmd[0] == 's') {
                cmd_left = cmd_right = 0;
                Serial.println("Stop");
            } else if (cmd[0] == 't') {
                Serial.printf("eRPM L=%.0f R=%.0f\n",
                              dshot_erpm_left(), dshot_erpm_right());
            } else if (cmd[0] == 'd') {
                dshot_print_telem_debug();
            } else if (cmd[0] == 'v') {
                dshot_dump_rx_frames();
            }
        } else if (ci < 31) { cmd[ci++] = c; }
    }
    dshot_send(cmd_left, cmd_right);
    delay(1);

#else
    // Levels 3-4 and production: FreeRTOS tasks do all work
    vTaskDelay(portMAX_DELAY);
#endif
}

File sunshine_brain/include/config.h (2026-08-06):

#pragma once
#include <stdint.h>

// ── SPI pins
// ────────────────────────────────────────────────────────────────── FSPI →
// ADXL375
#define PIN_ADXL_CS 10
#define PIN_ADXL_MOSI 11
#define PIN_ADXL_SCK 12
#define PIN_ADXL_MISO 13
// INT pins (not used in polled mode, reserved)
#define PIN_ADXL_INT1 8
#define PIN_ADXL_INT2 9

// HSPI → LIS3MDL
#define PIN_MAG_CS 18
#define PIN_MAG_MOSI 15
#define PIN_MAG_SCK 16
#define PIN_MAG_MISO 17
#define PIN_MAG_DRDY 14
#define PIN_MAG_INT 21

// ── DShot
// ─────────────────────────────────────────────────────────────────────
#define PIN_DSHOT_LEFT 4   // S1
#define PIN_DSHOT_RIGHT 5  // S2
// AM32 2.x auto-detects BDSHOT from the inverted CRC — no configurator setting
// needed.
#define DSHOT_BIDIRECTIONAL 1

// ── Battery ADC
// ─────────────────────────────────────────────────────────────── ADC1_CH7 =
// GPIO7, connected to battery voltage divider (R_high=2k, R_low=1k)
#define PIN_BATT_ADC 7
// V = adc_raw * (3.3/4095) * (R_high+R_low)/R_low = adc_raw * (3.3/4095) * 3.0
static constexpr float BATT_ADC_SCALE = (3.3f / 4095.0f) * 3.0f;
// Battery low-pass cutoff. The raw ADC carries a strong ~50 Hz (2×-spin) EMI
// tone
// (~±100 mV) that swamps the 20 mV telemetry resolution and makes batt_voltage
// unusable. A single-pole IIR at this cutoff rejects it (~10× at 50 Hz) while
// still passing real current-draw sag (tens–hundreds of ms). Raise for snappier
// sag response, lower for a smoother trace. (Oversampling within the 1 kHz tick
// would NOT help — the noise is a slow spin-synchronous tone, not fast ADC
// noise.)
static constexpr float BATT_LP_HZ = 6.0f;

// ── LED
// ───────────────────────────────────────────────────────────────────────
#define PIN_LED 38
// Duty levels for analogWrite (8-bit, 0..255).
// Armed brightness: the MELTY heading flash and the TANK solid-on "armed"
// indicator. ALWAYS full brightness — the flash is only shown while spinning,
// where it must be visible in daylight, so it's never dimmed by bringup level.
#define LED_DUTY_ACTIVE 255
// DISABLED "breathe" and the sensor-init-error blink: a dim "board alive"
// indicator. Kept low at all times (the robot is stationary on a desk when
// these show), independent of bringup level. Tune to taste.
#define LED_DUTY_IDLE 40

// ── Timing
// ────────────────────────────────────────────────────────────────────
static constexpr uint32_t LOOP_INTERVAL_US = 1000;  // 1 kHz
static constexpr uint32_t CTRL_WATCHDOG_MS = 500;   // no ctrl → DISABLED

// ── Motor direction
// ─────────────────────────────────────────────────────────── Set to true to
// invert a motor's DShot output (mirrors forward↔reverse around DSHOT_NEUTRAL).
// Use this when wiring or AM32 direction can't be changed. In MELTY mode with
// no translation input, both motors spinning "forward" should produce CCW body
// rotation (viewed from above). If the robot spins CW, flip both. If only one
// motor spins the wrong way, flip that one. See BRINGUP.md Level 2 for the
// verification procedure.
static constexpr bool MOTOR_LEFT_INVERT = false;
static constexpr bool MOTOR_RIGHT_INVERT = true;

// ── ESP-NOW
// ───────────────────────────────────────────────────────────────────
static constexpr uint8_t ESPNOW_CHANNEL = 1;
// Receiver MAC — AUTO-LEARNED at runtime from the receiver's control packets
// (telemetry.cpp), so this does NOT need to be filled in. It is only the
// pre-pairing bootstrap: broadcast (FF:..) until the first control packet
// arrives, after which telemetry switches to UNICAST to the learned MAC (→ MAC
// ACK + hardware retransmit = no lost frames). Leave as broadcast unless you
// want to hard-pin a specific receiver.
static const uint8_t RECEIVER_MAC[6] = {0x44, 0x1B, 0xF6, 0xD6, 0x46, 0x50};

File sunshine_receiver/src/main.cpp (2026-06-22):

// src/main.cpp
// Receiver firmware: bridges brain (ESP-NOW) ↔ host app (USB serial)
//
// Core 0: FreeRTOS task — ESP-NOW RX callback (registered via esp_now, runs on
//         Core 0 by default in Arduino framework)
// Core 1: bridge_task — USB TX/RX + 500 Hz timer (timer runs on its own task
//         but we drive the USB I/O from this loop)

#include "config.h"
#include "protocol.h"
#include "led_status.h"
#include <Arduino.h>
#include <WiFi.h>
#include <esp_now.h>
#include <esp_wifi.h>
#include <freertos/FreeRTOS.h>
#include <freertos/task.h>

// ── Bridge task (Core 1) ──────────────────────────────────────────────────────
static void bridge_task(void *) {
    for (;;) {
        usb_bridge_tick();
        vTaskDelay(pdMS_TO_TICKS(1));  // yield ~1 ms between ticks (USB is buffered)
    }
}

void setup() {
    Serial.begin(921600);
    delay(100);

    // ── Status LED (safe before WiFi/ESP-NOW) ─────────────────────────────────
    led_status_init();
    led_status_set(LED_BOOT);

    // ── WiFi: STA mode, fixed channel 1, max power ────────────────────────────
    WiFi.mode(WIFI_STA);
    WiFi.disconnect();
    esp_wifi_set_channel(ESPNOW_CHANNEL, WIFI_SECOND_CHAN_NONE);
    esp_wifi_set_max_tx_power(84); // 21 dBm, maximum

    // Print this receiver's STA MAC so it can be hard-coded as RECEIVER_MAC in the
    // brain's config.h (deterministic unicast pairing for a multi-device arena).
    Serial.printf("RECEIVER STA MAC: %s  (set as RECEIVER_MAC in brain config.h)\n",
                  WiFi.macAddress().c_str());

    // ── ESP-NOW init ──────────────────────────────────────────────────────────
    if (esp_now_init() != ESP_OK) {
        Serial.println("ESP-NOW init failed");
        // Latch red blink on the status LED to signal a fatal error.
        led_status_set(LED_ERROR);
        while (true) {
            led_status_tick();
            delay(5);
        }
    }
    esp_now_set_pmk((uint8_t *)"pmk_not_used_000"); // required call; PMK unused

    // ── Initialise subsystems ─────────────────────────────────────────────────
    espnow_rx_init();
    espnow_rx_register_callback();
    usb_bridge_init();

    // ── Start bridge task pinned to Core 1 ───────────────────────────────────
    xTaskCreatePinnedToCore(bridge_task, "bridge", 8192, nullptr, 5, nullptr, 1);

    Serial.println("Receiver ready");
}

void loop() {
    // All work is in bridge_task and the esp_timer callback.
    // loop() runs on Core 1 too but we keep it empty.
    vTaskDelay(portMAX_DELAY);
}

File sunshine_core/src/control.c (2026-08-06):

/* src/control.c */
#include "sunshine_core.h"
#include <math.h>

#define M_PI_F 3.14159265f

/* Wheel-speed cap policy (control policy, deliberately NOT in the header next to
 * the per-build physical parameters — a different robot does not retune these).
 * Outside the plausibility window the battery reading is not believable (a stuck
 * ADC, an unpopulated divider, a garbage frame), and the cap is SKIPPED ENTIRELY.
 * The cap divides by v_batt, so a stuck-low reading would compute a near-zero
 * ceiling and silently disarm the weapon mid-match. It must therefore fail OPEN,
 * never closed: a wrong battery reading costs us the overspeed bound, a closed
 * failure costs us the fight. */
#define RADS_TO_RPM     (60.0f / (2.0f * M_PI_F))
#define CAP_VBATT_MIN_V 5.0f
#define CAP_VBATT_MAX_V 10.0f

static float clampf(float v, float lo, float hi) {
    return v < lo ? lo : (v > hi ? hi : v);
}

static float wrap_to_pi(float a) {
    /* O(1) wrap to [-pi, pi] — see kalman.c. The old iterative version's cost
     * scaled with |a|, so once kf_theta grew large this ran thousands of loops
     * every tick and blew the 1 kHz budget. */
    return remainderf(a, 2.0f * M_PI_F);
}

/* Balanced bipolar trapezoid for MELTY translation.
 * The + and - plateaus are 180° apart and equal area, so the differential has
 * zero mean and wave(phase+pi) == -wave(phase). DRIFT_PLATEAU_WIDTH is the
 * fraction of a full rotation spent on each plateau; the two ramps fill the
 * rest of the cycle to preserve half-wave symmetry. */
static float drift_wave(float phase) {
    float p = wrap_to_pi(phase);
    float plateau = clampf(DRIFT_PLATEAU_WIDTH, 0.0f, 0.49f);
    float half_flat = plateau * M_PI_F;
    float ramp = M_PI_F - 2.0f * half_flat;
    float ap = fabsf(p);

    if (ap <= half_flat) return 1.0f;
    if (ap >= M_PI_F - half_flat) return -1.0f;
    if (ramp <= 1e-6f) return p >= 0.0f ? -1.0f : 1.0f;

    if (p > 0.0f)
        return 1.0f - 2.0f * (p - half_flat) / ramp;
    return 1.0f + 2.0f * (p + half_flat) / ramp;
}

static float map_to_dshot(float v) {
    /* v in [-1, 1] → AM32 3D DShot value.
     * Forward [1048..2047]: v=0 → 1048 (stopped), v=+1 → 2047 (max fwd).
     * Reverse [48..1047]:   v→0⁻ → 48 (min rev),  v=-1 → 1047 (max rev). */
    if (v >= 0.0f) return DSHOT_NEUTRAL + v * (DSHOT_MAX    - DSHOT_NEUTRAL);
    else           return DSHOT_MIN     + (-v) * (DSHOT_NEUTRAL - 1.0f - DSHOT_MIN);
}

/* MELTY wheel-speed cap. Returns `base` clamped to the DShot value whose no-load
 * wheel speed equals the speed the ground demands plus a fixed slip allowance.
 * Without it the wheels run 1.3–2.3× the rolling speed, and each landing dumps
 * that surplus kinetic energy in as an impulsive traction spike (the bounce).
 *
 * The rate reference is the mag-driven kf_omega and NEVER omega_from_accel. The
 * accel is corrupted precisely when the cap matters most: airborne it sees
 * free-fall, and on touchdown it sees the impact, so the accel-derived rate spikes
 * and would RAISE the cap at the exact instant the wheels are about to hit. The
 * mag rotation rate measures rotation directly and is immune to linear
 * acceleration, so it is the only trustworthy reference during a bounce.
 *
 * The reference is max(..., SUNSHINE_MAG_MIN_OMEGA) rather than "switch the cap
 * off when unlocked", because losing lock does not mean ω is unknown. Lock is
 * DEFINED as |ω| > SUNSHINE_MAG_MIN_OMEGA, so "not locked" itself carries the
 * bound |ω| ≤ SUNSHINE_MAG_MIN_OMEGA — the cap never switches off, it falls back
 * to the threshold, and the runaway stays bounded even before lock. And because
 * locked implies |kf_omega| > the threshold, this single max() is CONTINUOUS
 * across the lock boundary: no step in commanded speed the instant the mag locks.
 *
 * v_batt must appear because the ESC is an open-loop voltage source: speed is set
 * by duty × V_batt, and the pack moved 7.80–8.39 V inside one run — a 7% speed
 * swing for an unchanged DShot value. A cap in pure DShot units would drift with
 * the battery over a match.
 *
 * Accepted consequence: a robot with a DEAD magnetometer never locks and so is
 * held at the unlocked ceiling forever (≈1194 DShot at 8.2 V) — it will not spin
 * up. That is the right trade, since a MELTY robot with no heading reference is
 * undriveable anyway, but it converts "degraded but spinning" into "will not spin
 * up" and is therefore documented in BRINGUP.md so bringup sees it first. */
static float melty_speed_cap(const SunshineState *s, const SunshineVars *v, float base) {
    /* Written as a positive-range test so a NaN battery also fails open. */
    if (!(v->batt_voltage >= CAP_VBATT_MIN_V && v->batt_voltage <= CAP_VBATT_MAX_V))
        return base;

    /* Same lock condition brain.c uses to decide whether to trust the mag rate. */
    int locked = v->mag_valid && fabsf(s->spin_rate_lp) > SUNSHINE_MAG_MIN_OMEGA;

    float w_ref    = fmaxf(locked ? fabsf(s->kf_omega) : 0.0f, SUNSHINE_MAG_MIN_OMEGA);
    float w_cap    = w_ref * (WHEEL_CENTER_M / WHEEL_RADIUS_M)   /* rolling rate    */
                     + WHEEL_SLIP_ALLOW_MS / WHEEL_RADIUS_M;     /* + slip allowance */
    float v_needed = (w_cap * RADS_TO_RPM) / MOTOR_KV_RPM_PER_V;
    float cap      = DSHOT_NEUTRAL + (v_needed / v->batt_voltage) * (DSHOT_MAX - DSHOT_NEUTRAL);

    return fminf(base, fmaxf(cap, DSHOT_NEUTRAL));
}
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

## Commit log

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2026-05-27 feat(core): implement float16 conversion and unit helpers
    - Add utils.c with sunshine_f16_to_f32, sunshine_f32_to_f16,
    sunshine_accel_to_ms2, sunshine_mag_to_ut, sunshine_batt_to_v,
    and sunshine_schema_version
    - Add test_utils.c with 14 tests covering float16 round-trip (0.5%
    tolerance) and all unit conversion helpers
    - Add stub files for kalman.c, derot_filter.c, control.c, brain.c
    so the static library compiles while other tasks are pending
    [brain.c, control.c]
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2026-05-27 fix(brain): correct PIN_BATT_ADC for ESP32-S3, fix LIS3MDL ODR/mode conflict
    - PIN_BATT_ADC: PCB routes battery divider (VSENSE net) to IO39, but GPIO 39
    is digital-only on ESP32-S3 (ADC1=GPIO1-10, ADC2=GPIO11-20). Changed to
    GPIO 7 (ADC1_CH6) as placeholder; hardware revision needed to reroute VSENSE.
    - LIS3MDL: replaced setDataRate(1000_HZ) + setPerformanceMode(UHP) with
    setDataRate(155_HZ) only. Library source confirms 155_HZ internally calls
    setPerformanceMode(UHP) before writing ODR bits — the prior 1000_HZ call
    forced LP mode then UHP overwrote it, leaving an undefined register state.
    [config.h, lis3mdl.cpp]
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2026-05-27 fix(brain): telemetry bounded mutex timeout, send error check, null assert, stale constant
    [config.h, telemetry.cpp]
2026-05-27 fix(brain): nav loop overrun flag per-tick, t_next resync before printf, batt clamp -128
    [nav_control.cpp]
2026-05-27 feat(brain): integrate all subsystems, full bringup level support
    - Replace main.cpp stub with definitive integrated version
    - Handle all 5 bringup levels and production in one file
    - error_halt() with N-blink LED patterns (1=ADXL, 2=LIS3MDL, 3=DShot)
    - Bringup 1-2: Arduino loop() for CSV output / DShot interactive test
    - Bringup 3+: FreeRTOS tasks pinned to cores (telemetry→Core0, nav→Core1)
    - Fix sunshine_core.h: add extern "C" guards so C++ TUs (nav_control.cpp)
    link correctly against the C-compiled library objects
    [main.cpp, sunshine_core.h]
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2026-05-27 feat(receiver): define USB serial framing protocol
    - Fix BRAIN_MAC placeholder to 0x00 (0xXX is invalid C)
    - Pin espressif32 to 6.0.0 (>=6.0.0 resolves to broken pioarduino fork)
    - Add .gitignore for PlatformIO build artifacts
    [config.h, main.cpp]
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2026-05-28 feat(app): Tauri scaffold + build.rs + sunshine_core FFI layer
    Sets up the sunshine_app Tauri 2.x + React-TS project skeleton with
    pnpm as package manager, compiles sunshine_core C files via cc crate
    in build.rs, adds Rust FFI structs matching sunshine_core.h layout,
    and stubs all modules required by lib.rs (pipeline, controls, commands,
    protocol, serial, logging, replay, simulation). Build verified 0 Rust
    errors, producing sunshine_app.app and .dmg.
    [ffi.rs]
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2026-05-28 fix(core): SunshineVars packed + uint8_t flags; add all 5 docs
    - sunshine_core.h: SunshineVars gets __attribute__((packed)) and
    bool→uint8_t for led_on/accel_saturated/mag_valid/loop_overrun;
    remove now-unused stdbool.h include
    - brain.c, control.c: bool false→0 to match uint8_t field type
    - ffi.rs: SunshineVars bool→u8, #[repr(C,packed)], add size assert
    - docs/ARCHITECTURE.md: codebase map for AI sessions/new contributors
    - docs/BRINGUP.md: step-by-step for all 5 levels + platform notes
    (pioarduino URL workaround, IDF 4.4 RSSI limitation, MAC setup,
    DShot library substitution)
    - docs/TUNING.md: Kalman and MELTY drift tuning guide
    - docs/FILTER_MATH.md: centripetal→ω, sync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
    [brain.c, control.c, ffi.rs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]
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2026-06-07 DShot bidirectional telemetry decode fix + N16R8 board config
    - Decode GCR telemetry at 4/5 of the command bit period; real 3-bit runs
    were quantizing to 2 bits, the cause of the ~90% CRC-fail rate
    - Accept CRC-valid 0xFFF as the zero-eRPM "motor stopped" sentinel instead
    of tallying it as a CRC failure
    - Force an ESC reset with a brief LOW pulse in dshot_init so a warm brain
    reset re-arms AM32 without a physical power-cycle
    - Pin pioarduino platform to 55.03.38 (stable was a moving, flaky pointer);
    configure ESP32-S3-WROOM-1 N16R8 16MB flash + OPI PSRAM (brain + receiver)
    - Build shared sunshine_core sources directly; add idf_component.yml
    [dshot.cpp]
2026-06-07 Receiver: onboard RGB status LED for link/liveness state
    Add a non-blocking WS2812 status driver (led_status.{h,cpp}) and wire it
    into the bridge:
    - white breathe = boot/idle, red blink = fatal ESP-NOW init error
    - red breathe = no brain, amber = brain up but host silent, green = both live
    - brief flash per forwarded telemetry frame as an activity blip
    - millis-based breathing, writes throttled to ~60 Hz; error blink now ticks
    the LED inside the fatal-error loop instead of a bare delay
    [main.cpp]
2026-06-07 Seed replay from transmitted filter state; disconnect UI + fixes
    Replay seeding (the core fix):
    - brain: snapshot filter state BEFORE sunshine_step and push that with the
    frame, so telemetry carries "state at start of frame" as replay expects
    (pairing inputs with post-step state seeded replay one sample ahead)
    - pipeline: seed replay_state from the first ingested frame's state, re-armed
    on brain reconnect; also seed offline replay from the first logged state.
    Fixes the constant heading offset and connect-time omega spike from replay
    starting at a zeroed Kalman state
    - commands: arm the live seed before opening the port (no first-frame race)
    Connection UX:
    - add disconnect_serial c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
    [nav_control.cpp]
2026-06-07 1 kHz loop timing: faster sensor SPI, DShot600, profiling + replay polish
    Brain loop budget:
    - adxl375: bypass Adafruit driver on the hot path, burst-read DATAX0..DATAZ1
    at 5 MHz SPI_MODE3 (driver hardcodes 1 MHz, ~100 µs/read)
    - lis3mdl: raise SPI clock to 5 MHz (~5× shorter transfer)
    - dshot: DSHOT300 → DSHOT600, halving TX frame + blocking wait time
    - nav_control: per-section µs PROF print (adxl/mag/batt/ctrl/step/dshot/rest +
    worst-case over window), emitted inside the idle budget; remove once budget
    is comfortably met
    Host replay + UI:
    - pipeline: re-anchor replay_state from every LIVE packet's transmitted state
    instead of a one-shot seed — corrects slow dead-reckoning d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
    [adxl375.cpp, dshot.cpp, lis3mdl.cpp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]
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2026-06-07 Bringup L4: let TANK mode drive motors for nav tuning
    Split the old "zero dshot at levels 3-4" guard:
    - Level 3 (telemetry bringup) keeps FORCE_DSHOT_ZERO — no motion at all
    - Level 4 (nav tuning) gets TANK_ONLY_OUTPUT: only TANK mode drives so you can
    spin the robot to tune the Kalman/derot filters; DISABLED and MELTY stay
    zeroed (MELTY isn't tuned until Level 5). Production (L0) still drives all modes
    - update bringup.h level legend and BRINGUP.md Level 4 setup notes (props off)
    [nav_control.cpp]
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2026-06-14 dshot: sanitise corrupt eRPM telemetry decodes
    Bidirectional-DShot frames carry only a weak 4-bit GCR checksum, so a few
    percent decode to garbage — implausibly low values or tiny periods that yield
    ~6e7 eRPM and overflow the float16 telemetry field to +inf (the dropouts and
    inf spikes in recorded logs).
    Add a three-stage ErpmFilter per motor, exploiting the flywheel's high inertia
    (true eRPM changes slowly, so any large single-sample jump is a decode error):
    1. range-gate to [0, ERPM_MAX] — kills the +inf source
    2. deviation-gate vs running median (only once clearly spinning) — rejects
    the low/high garbage cloud a plain median can't outvote
    3. median-5 over accepted decode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
    [dshot.cpp]
2026-06-14 lis3mdl: 1000 Hz ODR so the 1 kHz loop reads a fresh mag sample each tick
    At 155 Hz the same conversion was re-read ~6× per tick while est_theta
    advanced 20–40° at high spin, smearing the synchronous derotation (|derot|
    collapsed 25→6 µT above ~500 RPM). 1000 Hz (LP mode + FAST_ODR) delivers one
    fresh sample per tick — exactly what the fs=1000 Hz LP4 derot filter assumes;
    LP-mode per-sample noise is dominated out by that filter's heavy averaging.
    Keep using setDataRate alone (it sets LP + FAST_ODR); a separate
    setPerformanceMode call would clobber FAST_ODR. Noted a BDU/tearing follow-up
    to check live if the spin-up trace shows isolated axis spikes.
    [lis3mdl.cpp]
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2026-06-22 core: open-loop mag tracking band-pass heading; fix MELTY precession
    Replace synchronous-demodulation derotation (derot_filter.c) with an open-loop
    magnetometer heading (mag_heading.c): a 2nd-order RBJ band-pass centred on the
    spin frequency (from kf_omega) isolates the Earth-field sine — its DC zero kills
    hard-iron + averaged ESC-current offset, and the skirt rejects the fs/6≈167 Hz
    LP-mode sampling tone a fixed filter can't. Bandwidth is a constant fraction of
    fc (Q=1.5 → half-BW ≈ 33% of spin) so the true spin stays in-band at any speed
    and the group delay is a constant offset theta_offset absorbs. heading =
    atan2 of the band-passed axes → cannot drift.
    Kalman: the accel rate i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
    [brain.c, ffi.rs, mag_heading.c]
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2026-06-22 core: fix mag band-pass false-lock; enlarge telemetry ring
    Mag heading (the real fix): centre the tracking band-pass on omega_from_accel
    (a direct accel measurement) instead of kf_omega. The band-pass output sets
    kf_theta, which feeds kf_omega back through the Kalman cross-covariance, so
    centring on kf_omega closes a loop whose per-tick coefficient modulation
    parametrically FALSE-LOCKS the recovered heading at half the true spin rate.
    omega_from_accel is loop-independent, breaking that loop; the accel's few-%
    bias only attenuates (LTI band-pass preserves frequency), never biases the
    angle. Falls back to kf_omega only during brief accel saturation.
    With the heading recovered fully open-loop,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
    [brain.c, mag_heading.c, nav_control.cpp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]
2026-06-22 telemetry: reliable unicast delivery (MAC ACK + retransmit) end-to-end
    Broadcast ESP-NOW has no ACK/retry, so any collision — including the
    half-duplex receiver being mid-control-TX — was a permanent lost frame and
    broke replay. Switch telemetry to UNICAST so the WiFi MAC ACKs and retransmits
    in hardware:
    - pairing: prefer a hard-coded RECEIVER_MAC (config.h) — deterministic, and we
    then reject control from any other MAC (multi-device arena). If left
    broadcast, auto-learn the receiver MAC from its control packets (bench
    bring-up). Add the unicast peer alongside broadcast so there's no peer gap;
    receiver now prints its STA MAC at boot for hard-coding
    - gap-align the send: a bina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
    [config.h, main.cpp, nav_control.cpp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]
2026-06-22 telemetry: TX flow control + drop sends when the link is down
    Two robustness fixes on top of unicast telemetry, both preventing an ESP-NOW TX
    queue overflow (ESP_ERR_ESPNOW_NO_MEM) that would stall the ring drain:
    - One frame in flight at a time: wait on a tx_done_sem (given by the send
    callback) before the next esp_now_send, so the ESP-NOW TX queue can't back up
    when the ring bursts. Primed once at init; 50 ms fail-safe timeout, and a
    failed send gives the sem back immediately (no callback will fire).
    - Don't transmit while the receiver is absent: track last_ctrl_ms from the
    control stream; if no control for >200 ms the receiver is off → there's
    nowhere to send, so drop the (al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
    [telemetry.cpp]
2026-06-23 telemetry: two-stage assemble/send split; LED beacon survives high spin
    Telemetry: split into two Core-0 tasks decoupled by a frame FIFO (48 frames ≈
    1 s at 50 Hz):
    - Stage A (telemetry_task): drains the 1 kHz input ring and assembles whole
    frames, NEVER blocking on TX. RF congestion / unicast retries can no longer
    back up the input ring → fixes input loss under congestion. Link-down frames
    are dropped here (ring already drained).
    - Stage B (telemetry_send_task): dequeues frames and does flow-control +
    gap-align + unicast send; it may block freely without stalling Stage A.
    Add a frames_dropped counter (FIFO full = sustained link-up congestion) to the
    PROF line; spawn the second t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
    [control.c, main.cpp, nav_control.cpp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]
2026-06-23 control: balanced bipolar MELTY drift wave; replay CSV adds eRPM + stored state
    MELTY translation: replace the asymmetric trapezoid() with a balanced bipolar
    drift_wave(). The + and - plateaus are now 180° apart with equal area and the
    ramps fill the rest of the cycle, so the differential is zero-mean and
    half-wave symmetric (wave(φ+π) == -wave(φ)) — no net torque bias that would
    skew the spin. Tuning:
    - DRIFT_PLATEAU_WIDTH (fraction per plateau) replaces DRIFT_PULSE_WIDTH +
    DRIFT_RAMP_WIDTH
    - scale the differential by the available DShot HEADROOM (min of head/room
    either side of base), not by spin_span, so translation can't clip
    asymmetrically near full spin
    - add DRIFT_PHASE_OF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
    [control.c, replay.c, sunshine_core.h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]
2026-07-19 core: schema v4 spin-direction (sign) recovery; batt LP; non-blocking USB
    Spin SIGN from the magnetometer (schema v4): the accelerometer measures only
    |ω| (centripetal magnitude) and can't tell CW from CCW, so when the robot is
    inverted the heading counter-rotated. Add SunshineState.mag_ang_prev +
    spin_rate_lp: mag_heading.c tracks a low-passed SIGNED mag rotation rate, and
    brain.c copies that sign onto omega_from_accel before the Kalman rate update so
    kf_omega / kf_theta wind the correct way in either orientation. mag_valid now
    gates on |kf_omega| so a correct negative rate doesn't disable the mag. Defaults
    to + before the mag locks (old behaviour); true sign within ~50 ms.
    Battery low-pa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
    [brain.c, config.h, ffi.rs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]
2026-07-19 core: schema v5 (int16 battery, mag-rate heading); app Variables + coarse real series
    Translation localization: drive the Kalman rate from the magnetometer's own rotation
    rate (spin_rate_lp) while the mag is valid, instead of the accel magnitude. Linear
    body acceleration during a drift adds a once-per-rev term to the accel that both
    wobbles the rate (integrating into ~30 deg heading swings — the "LED fluctuates")
    and biases it high (Jensen -> slow drift); the B-field's rotation has neither
    problem. Replay on real logs: translation LED excursion 33->23 deg (toward the ~19
    deg pure-spin baseline), drift down to the pure-spin level, no penalty during rapid
    spin changes, pure spin unchanged. T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
    [brain.c, ffi.rs, mag_heading.c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]
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2026-08-02 control: cap MELTY wheel speed to rolling + slip allowance; eRPM NaN for unmeasurable
    The robot bounces: the wheels spin up far past what the ground demands, then get
    dragged back down on every touchdown, dumping stored wheel energy as an impulsive
    traction spike that throws it airborne again. Measured on translation2.sun, wheel
    eRPM ran a median 1.30x and a p95 2.27x above the no-slip speed.
    The ESC is an open-loop voltage source, so wheel speed is duty x V_batt x KV.
    Invert that: cap the MELTY base command at the DShot value whose no-load speed is
    the ground-demanded rolling speed plus a fixed 1.0 m/s slip allowance. A fixed
    slip SPEED (not a percentage) is the right shape — traction fo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
    [control.c, dshot.cpp, nav_control.cpp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]
2026-08-04 control: compensate measured ~17 ms actuation lag; add translation_lag.py
    Root cause of "motors modulate but the robot only wobbles": the wheel-speed
    response lags the DShot differential by a pure ~20 ms time delay (18-24 ms
    across 24 windows of the translation2 log, both spin directions, zero constant
    offset), ~3 ms of which is eRPM telemetry filtering. Uncompensated that is a
    110-150 degree force-direction error at 1000-1300 RPM. Set
    DRIFT_PHASE_LEAD_S = 0.018 (was 0) and lock it in with waveform-advance tests.
    tools/replay/translation_lag.py automates the measurement (time-domain
    cross-correlation, alias-free unlike erpm_bandwidth.py's demodulation, with a
    constant-offset residual check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
    [sunshine_core.h, test_control.c]
2026-08-04 core+app: single-source all per-robot constants in sunshine_core.h
    Move every physical/plant constant out of simulation.rs into the core header's
    new "robot plant / environment" block (mass, MOI, wheel inertia, phase
    resistance, pack model, Earth field, hard-iron, mag HF tone, SIM_* fudge
    factors). The app's build.rs now parses the header and generates the Rust
    constants into OUT_DIR at build time, so the sim cannot drift out of sync and
    porting to a new robot is an edit to one file. BRINGUP.md porting section
    updated accordingly.
    [simulation.rs, sunshine_core.h]
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2026-08-06 control: un-bias translation slip, fade drift at low spin, soften trapezoid
    Diagnosed from the 2026-08-06 logs (Bounce_control/Moreamplitude/noscrews):
    - Slip un-bias: the cap's fixed +1 m/s slip allowance was a translation
    DEAD ZONE — with both wheels parked in forward saturation, the drift
    wave's first ~1 m/s of differential produced no force (light presses:
    audible modulation, no movement), and force-producing amplitudes ran
    1.6-5.7 m/s of slip whose surplus KE kicked the robot airborne on every
    landing. The allowance now scales by (1 - drive_mag): full stick centres
    the wave on ZERO slip — advancing wheel pushes, retreating wheel brakes,
    force proportional to the stick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
    [control.c, replay.c, sunshine_core.h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]
2026-08-07 control: keep a spin-maintenance remnant of the slip allowance at full stick
    The 2026-08-07 Nosliphopefully log shows the full un-bias starves the spin:
    holding the pack against drag needs ~0.5 m/s of slip, so with zero bias a
    held stick bled omega down until the low-spin fade partially restored the
    allowance — a stable crawl at ~75 rad/s (measured mean slip +0.53 m/s) for
    30 s of held W. DRIFT_UNBIAS_FRAC=0.5 keeps half the allowance at full
    stick: pays the measured drag bill, negligible against the multi-m/s wave
    swing (no dead-zone return).
    [control.c, sunshine_core.h, test_control.c]
2026-08-07 control: halve DRIFT_AMPLITUDE — wheel-rotor gyro torque is the tilt driver
    Every onset strike survived the bias/plateau/un-bias changes because none of
    them altered the commanded wheel-speed swing. Body rotation x the wave's
    phase-locked wheel-momentum modulation produces a steady world-frame tilting
    torque ~ I_w * omega * dw_wheel: ~0.17 N*m at amplitude 0.60 and omega=150 —
    4x the F*h moment from the translation force itself, and its predicted
    tilt-to-strike time (~0.1-0.2 s) matches every measured onset. Ground force
    saturates at ~±1 m/s of slip, so 0.30 (swing ~±1.9 m/s) keeps full
    translation force while halving the dominant tilt torque.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
    [sunshine_core.h]
2026-08-07 control: DRIFT_AMPLITUDE 0.30 -> 0.45 — inside the measured force/tilt box
    Per-drive-level analysis of the 2026-08-07 New_data log: at 0.30 the wave
    swing (1.4 m/s at full stick) barely clears the 0.5 m/s spin bias plus the
    ~1 m/s tire-saturation width, so the retreating wheel hardly brakes —
    realized wheel diff ~0.5 m/s, dead zone below ~50% deflection, robot creeps
    erratically. 0.45 puts the swing at ~2.1 m/s: both wave halves saturated
    (real force) while keeping the wheel-rotor gyro tilt torque at ~55% of the
    0.60 config (whose strikes came in ~0.15 s).
    [sunshine_core.h]
2026-08-07 control: gate translation to the plant's bandwidth; full amplitude in-band
    The New3 log (phase-binned wheel speed vs commanded slip) proves the dead
    zone is PLANT BANDWIDTH, not tuning: commanded ±2 m/s slip swing realizes
    only ±0.4 m/s at omega 130-150 — matching erpm_bandwidth.py's gain curve
    (0.31 of commanded at 15 Hz spin, 0.19 at 22 Hz). Above ~20 Hz the braking
    half of the wave never physically happens (zero differential force, "sound
    but no movement") while the motor torque still reacts gyroscopically on the
    chassis (tilt, floor strikes). So:
    - DRIFT_OMEGA_ROLLOFF_LO/HI 105/135: translation authority rolls off to
    zero above the band the wheels can actually track. Translate at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
    [control.c, sunshine_core.h, test_control.c]
2026-08-07 control: translation spin governor — a held stick brakes into the band
    The Limitedspeed log shows the rolloff alone strands the driver: the cap
    grants rolling + allowance, so spin settles at the THROTTLE's no-load
    equilibrium (41% throttle -> ~168 rad/s), 100% of stick-held time sat above
    the 135 rad/s rolloff, and the stick was simply dead. Holding the stick now
    IS the request to translate: the cap's rate reference blends from
    |kf_omega| down to DRIFT_TRANSLATE_OMEGA_RADS (100) with raw deflection,
    actively braking the robot into the band (~0.5 s from 165) where the
    rolloff grants full authority; releasing resumes throttle-equilibrium spin.
    Uses pre-fade deflection — post-fade drive is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
    [control.c, sunshine_core.h, test_control.c]
2026-08-07 control: remove high-spin rolloff + spin governor; prep force-direction test
    The rolloff/governor rested on reading high-spin eRPM attenuation as an
    ESC/plant bandwidth limit. That reading is confounded: a GRIPPING tire pins
    wheel speed near rolling regardless of command, so speed attenuation can
    mean force IS being transmitted. Melty practice translates at 2K+ RPM with
    less edge clearance than this robot (5.8 mm vs ~3 mm typical), so forcing
    spin below ~1000 RPM treated a symptom.
    Prime suspect is now the force DIRECTION: DRIFT_PHASE_LEAD_S was derived
    from the wheel-SPEED response (~20 ms, speed integrates torque), but grip-
    regime force follows commanded voltage nearly instantly — if t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
    [control.c, sunshine_core.h, test_control.c]
2026-08-07 control: fix translation force direction — measured offset + slip-sign lag
    Root cause of the terrible translation, calibrated from first principles:
    1. A ~+210 deg constant error between commanded and physical force
    direction (likely a diff-sign flip from the 2026-08-06 motor-config
    change plus mount geometry). Invisible to every eRPM-based check (self-
    referential in the speed domain); only the on-floor drift-direction
    test could see it — DRIFT_PHASE_OFFSET_RADS = -2.62 cancels it.
    2. DRIFT_PHASE_LEAD_S was calibrated in the wrong domain: eRPM cross-
    correlation measures the wheel-SPEED lag (~20 ms, speed integrates
    torque), but the tires ride the cap's slip bias and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
    [sunshine_core.h, test_control.c]
2026-08-07 control+docs: amplitude 0.30 now that force aims right; bringup rewrite
    With direction fixed, amplitude no longer compensates for a misaimed force:
    it sets only the translation top-speed ceiling and the wheel-rotor tilt
    kick (low-speed force saturates at tire friction). 0.30 = ~±1.4 m/s
    ceiling, half the tilt kick of 0.60.
    BRINGUP Level 5 Step 4 rewritten: the old procedure set the lead from
    translation_lag.py (eRPM = speed domain, lags 2x the force) — the exact
    mistake that mis-aimed this robot for a month and self-concealed. The
    authoritative procedure is now the on-floor two-speed drift-direction test
    fitted with tools/melty_sim.py, yielding DRIFT_PHASE_OFFSET_RADS and the
    true force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
    [sunshine_core.h]
2026-08-07 docs: correct the offset provenance — original geometry error, not the wire fix
    User confirmed the Aug-6 motor-config commit compensated a physically
    flipped phase wire after reassembly; wire-flip + invert-flip cancel and are
    direction-neutral for the drift differential. The +210 deg offset is an
    original build convention error — consistent with translation never having
    been verified-good, including July.
    [sunshine_core.h]
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
